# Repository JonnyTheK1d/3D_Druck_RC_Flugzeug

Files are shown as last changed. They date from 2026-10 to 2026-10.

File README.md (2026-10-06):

# 1:8 RC-Flugzeug im Stil einer Cessna 172 – zum Selbstdrucken

Einmotoriger Hochdecker (Tragflächenstreben, Landeklappen, Bugradfahrwerk mit Radverkleidungen, Rückenflosse, Zugpropeller) im Maßstab **1:8** einer Cessna 172,
vollständig als **druckbare STL-Dateien** für Drucker ab **220 × 220 mm** Druckbett, parametrisch erzeugt (Python).

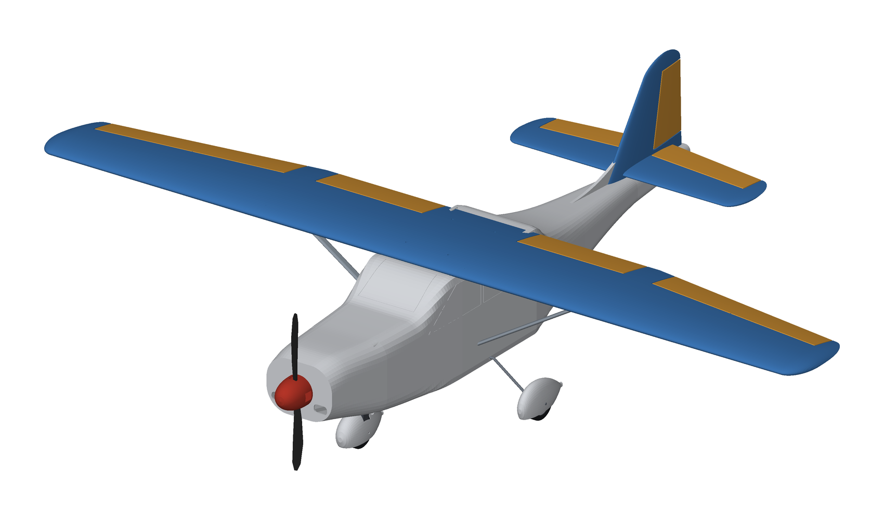
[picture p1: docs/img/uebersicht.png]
Übersicht


> **Status: Entwurf, nicht geflogen.** Geometrie, Druckbarkeit, Ruderfreigang und Schwerpunkt sind rechnerisch geprüft
> (siehe unten), das Flugzeug wurde aber **nicht gebaut und nicht geflogen**. Gewichte sind Schätzungen aus dem Modellvolumen.
> Plane Probe-Drucke und einen vorsichtigen Erstflug ein.

## Eckdaten

| | |
|---|---|
| Vorbild / Maßstab | Cessna 172, 1:8 |
| Spannweite / Länge / Höhe | **1375 mm** / ca. 1030 mm (mit Spinner) / 340 mm |
| Flügel | NACA 2412 (Unterseite ab 25 % eben, druckfreundlich), Tiefe 200 → 140 mm, **25,2 dm²**, Streckung 7,5, 2° Einstellwinkel |
| Leitwerk | Höhenleitwerk 425 mm (NACA 0010), Seitenleitwerk 175 mm hoch (NACA 0009) |
| Steuerung | Quer-, Höhen-, Seitenruder, **Landeklappen**, Gas, steuerbares Bugrad (7 Servos 9 g) |
| Antrieb (Empfehlung) | Außenläufer 28xx ≈ 1000 kV, 30-A-Regler, 3S 2200 mAh, Luftschraube 10×6″ |
<!-- AUTO:eckdaten -->
| Abfluggewicht (Schätzung) | **≈ 1,7 kg** (1,14 kg gedruckt + 0,55 kg Elektronik/Kohlefaser) |
| Flächenbelastung | ≈ 67 g/dm², Überziehgeschwindigkeit ≈ 9 m/s |
| Schwerpunkt (Rechenwert) | 60 mm hinter der Flügelvorderkante ≈ **32 % MAC**, Stabilitätsmaß ≈ 13 % MAC |
| Druckteile | **58 STL-Dateien / 66 Drucke**, größte Grundfläche 205 × 205 mm, höchstes Teil 93 mm |
| Material | ca. 985 g **LW-PLA**, 72 g PETG, 46 g PLA, 35 g TPU (siehe `docs/DRUCKEINSTELLUNGEN.md`) |
<!-- /AUTO:eckdaten -->

Die Auswertung stammt aus `docs/kennzahlen.json` (wird beim Generieren neu geschrieben).

## Ansichten

| | |
|---|---|
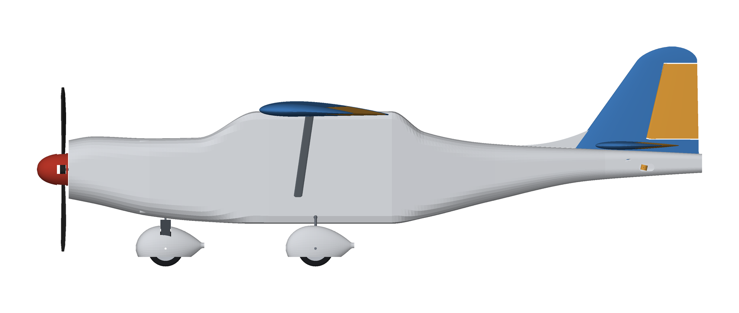
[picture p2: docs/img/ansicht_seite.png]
Seite
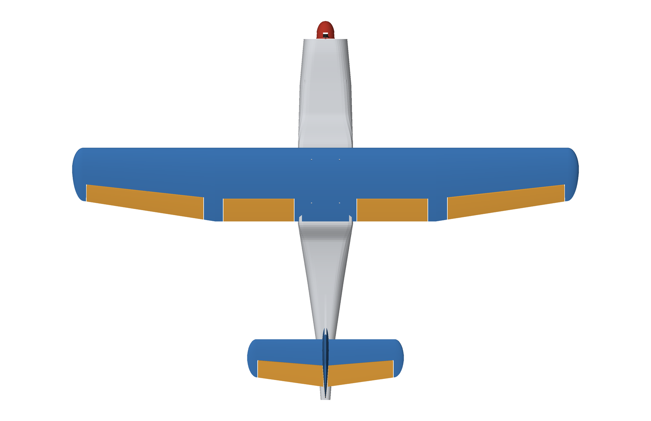
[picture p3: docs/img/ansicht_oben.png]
Oben
|  |  |
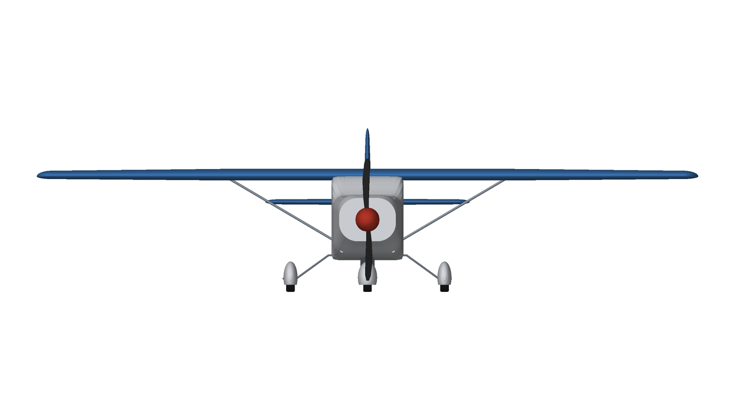
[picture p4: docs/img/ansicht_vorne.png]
Vorne
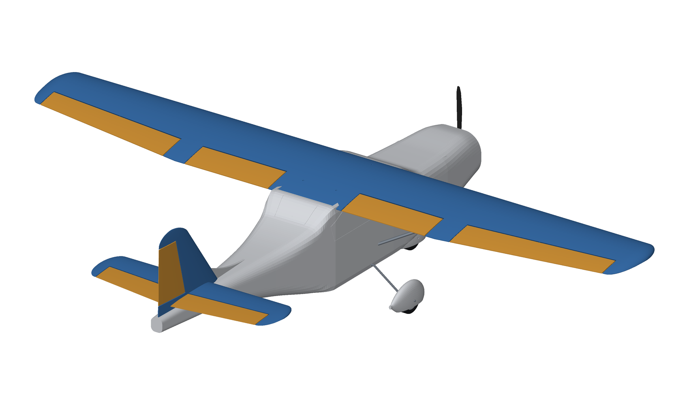
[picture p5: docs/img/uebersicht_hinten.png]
Hinten
|  |  |

## Inhalt des Repositories

| Pfad | Inhalt |
|---|---|
| `stl/` | **Alle druckfertigen STL** (bereits in Druckausrichtung), nach Gruppen: `Fluegel/`, `Querruder/`, `Leitwerk/`, `Rumpf/`, `Antrieb/`, `Fahrwerk/`, `Streben/`, `Kleinteile/` |
| `druckplatten/` | **34 fertig angeordnete Druckplatten (3MF)** für 220 × 220-mm-Betten, nach Material/Einstellung sortiert |
| `docs/DRUCKPLATTEN.md` | Welche Platte mit welchem Material und welchen Slicer-Einstellungen |
| `docs/DRUCKLISTE.md` | Teile, Stückzahl, Material, Druckgröße, Masse |
| `docs/DRUCKEINSTELLUNGEN.md` | Material, Slicer-Einstellungen, Ausrichtung, Nacharbeit |
| `docs/ZUKAUFTEILE.md` | Elektronik, Kohlefaser, Draht, Schrauben mit Maßen |
| `docs/BAUANLEITUNG.md` | Zusammenbau, Schwerpunkt, Ruderausschläge, Erstflug |
| `docs/FERNSTEUERUNG.md` | **Servos, Hebel-Löcher, Gestängelängen, Kanalbelegung, Senderprogrammierung** (aus dem Modell berechnet) |
| `docs/fahrwerk_biegeschablone.pdf` | Biegeschablone Hauptfahrwerk **1:1** (A4 quer) |
| `docs/stueckliste.csv`, `docs/kennzahlen.json` | Teileliste (CSV), Kennzahlen |
| `docs/img/` | Bilder (Ansichten, Explosionszeichnung, Teile-Übersicht) |
| `docs/viewer/` | **3D-Ansicht im Browser** (`index.html` öffnen, siehe unten) |
| `cessna/` | Generator (Python): Maße in `params.py`, Geometrie in `wing.py`, `fuselage.py`, `tail.py`, … |
| `tests/` | Automatische Prüfungen |

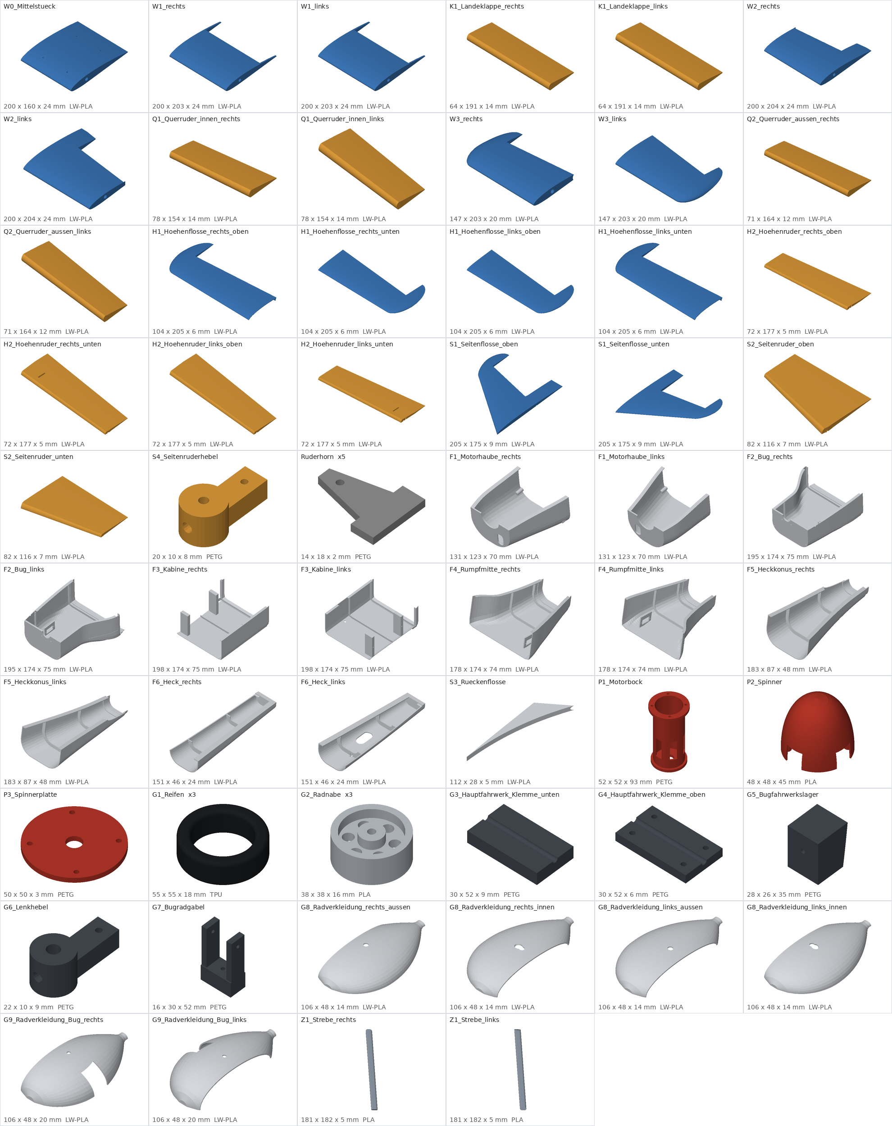
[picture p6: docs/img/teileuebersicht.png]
Teile-Übersicht


## So geht es los (Kurzfassung)

1. **Material besorgen:** ca. 1 kg LW-PLA (Flügel/Rumpf/Leitwerk), etwas PETG, PLA und TPU → `docs/DRUCKEINSTELLUNGEN.md`.
2. **Zukaufteile bestellen** → `docs/ZUKAUFTEILE.md` (Kohlefaser-Rohre 10/8 mm in 660 mm, Federstahldraht, 7 Mikroservos, …).
3. **Zuerst `W0_Mittelstueck` drucken und wiegen** (Soll laut `docs/DRUCKLISTE.md`) – damit Flow/Temperatur für LW-PLA richtig stehen.
4. Alle Teile drucken: die **3MF-Platten in `druckplatten/`** im Slicer öffnen (PrusaSlicer, Bambu Studio, OrcaSlicer, Cura),
   Einstellungen laut `docs/DRUCKPLATTEN.md`, slicen, drucken. Alternativ Einzelteile aus `stl/`. **Keine Stützen** außer
   optional unter der Flügelnase.
5. Zusammenbau nach `docs/BAUANLEITUNG.md` (Flügel → Leitwerk → Rumpf → Antrieb → Fahrwerk → Endmontage).
6. Fernsteuerung einbauen und programmieren → `docs/FERNSTEUERUNG.md` (Kanalplan, Gestängelängen, Ausschläge, Failsafe).
7. Schwerpunkt einstellen (siehe Tabelle oben), Ruder prüfen, **vorsichtig** einfliegen.

## 3D-Ansicht im Browser

`docs/viewer/index.html` zeigt das komplette Flugzeug interaktiv (Modell: `flugzeug.glb`, für die Seite base64-kodiert in `flugzeug.glb.txt`) (drehen, zoomen, Explosionsansicht, Baugruppen
ein-/ausblenden, Ruder bewegen). Auch die Zukaufteile sind zu sehen: Fahrwerksdrähte, Holm, Motor, Akku, Regler, Empfänger und die
7 Servos. Servohebel und Gestänge bewegen sich beim Ruderausschlag mit, das Bugrad lenkt mit dem Seitenruder.
„Rumpf durchsichtig“ zeigt die Anlenkungen im Rumpf. Wegen der Browser-Sicherheit die Seite über einen kleinen Webserver öffnen:

```bash
python -m http.server -d docs/viewer 8000   # dann http://localhost:8000 aufrufen
```

## Konstruktionsprinzip

* **Hohlbauweise für LW-PLA:** Außenhaut 1,1 mm (Flügel), 1,2 mm (Rumpf), 0,85 mm (Leitwerk) mit Rippen/Spanten;
  Holm = **CFK-Rohr 10/8 mm** durch alle Flügelabschnitte (gedruckte Holmhülsen), Verbinderstab in der Mitte.
* **Druckbett 220 × 220 mm:** Der Flügel besteht aus 4 Abschnitten je Seite/Mitte (je ≤ 202 mm Spannweite), der Rumpf aus
  6 Segmenten × links/rechts mit **Steckmuffen**, die Leitwerksflächen sind in Ober-/Unterschale geteilt.
* **Das Flügelmittelstück ist das Kabinendach** (wie bei der Cessna): Der Rumpf hat unter dem Flügel eine offene Kabine mit
  Spantbalken; der Flügel liegt in einem passgenauen Sattel und wird mit 4 Schrauben gehalten. Der Akku sitzt im Bugfach
  (Einschub von der Kabine aus) → wenige bewegliche Teile, Akku in Schwerpunktnähe.
* **Ruder mit Rundnase + Hohlkehle:** Querruder, Höhen- und Seitenruder lassen sich in der CAD-Prüfung um ±30° ausschlagen,
  ohne an Festteile zu stoßen (Scharnier: Gewebeband beidseitig).
* **Landeklappen** im Innenflügel (0–35° nach unten, eigenes Servo je Seite), **Radverkleidungen** für alle drei Räder
  und eine **Rückenflosse** wie bei der späten 172 – alle drei optional, aber typisch Cessna.
* **Fenster** sind als flache Gravuren (Lackiermaske) in den Rumpf eingearbeitet; Streben sind kosmetisch.
* **Druckfreundlich:** Alle Rumpfwände sind eben (stückweise linear verjüngt), damit sie flach auf dem Bett liegen; Teile
  sind so geteilt, dass keine Stützen nötig sind.

## Prüfungen (automatisch, `pytest`)

* alle Teile gültige geschlossene Volumenkörper, passen auf 220 × 220 × 250 mm (mit 4 mm Rand);
* **keine Überschneidungen** im Zusammenbau (paarweise Prüfung, inkl. Sättel für Flügel/Leitwerk);
* Ruderfreigang ±30° (Landeklappen ±35°); Holm liegt innerhalb des Profils;
* Schwerpunkt 22–34 % MAC, Stabilitätsmaß ≥ 8 %, Hauptfahrwerk ≥ 15 mm hinter dem Schwerpunkt;
* STL-Export wasserdicht (nach Rundung auf float32, wie beim Slicer), Einzelteile mit Boden auf z = 0.

## Anpassen und neu erzeugen

```bash
pip install -r requirements.txt
python -m cessna.build            # erzeugt STL, Druckliste, Bilder, Kennzahlen (~25 s)
python -m cessna.build --no-images --overlaps    # schneller Check inkl. Überschneidungsprüfung
python -m pytest -q tests         # Prüfungen
```

Alle Maße stehen in `cessna/params.py` (Flügel, Rumpftabelle, Leitwerk, Fahrwerk, Wandstärken, Druckbett). Der Generator
liefert zu jedem Lauf die Kennzahlen (Masse, Schwerpunkt, Neutralpunkt). Kleinere Druckbetten brauchen eine feinere
Teilung (Segmentgrenzen in `FUSE_SEGMENTS`, Abschnittsbreite `WING_PANEL_SPAN`); die Prüfung meldet jedes Teil, das nicht passt.

## Bekannte Grenzen / offene Punkte

* **Nicht geflogen.** Neutralpunkt/Stabilität sind Näherungsrechnungen (Standardmethode), keine Strömungsrechnung.
* Gewichte sind aus dem Volumen geschätzt (LW-PLA 0,55 g/cm³). Echte Teile können ±20 % abweichen → Schwerpunkt nach dem Bau
  ausmessen (Akkulage, Trimmblei im Bug).
* Der Flügel ist **einteilig** (1375 mm), nicht teilbar. Die Landeklappen sind einfache Drehklappen (keine Fowler-Klappen wie beim Original).
* Profil weicht für den Druck vom Original ab (flache Unterseite hinter 25 % Tiefe); die Nasenunterseite braucht ggf. einen
  kleinen Stützkeil oder Brim.
* Die Streben sind nur aufgeklebt (kosmetisch). Die Ruderscharniere sind Gewebeband (kein Kugelscharnier).
* Die Heckgestänge laufen in Kanälen durch die Spanten: Höhenruder als Bowdenzug mit schrägem Austritt links,
  Seitenruder über eine Ruderwelle in der Scharnierachse und den Hebel `S4` (Gestänge bleibt im Rumpf).
* Keine Lizenz festgelegt – wenn du das Repository öffentlich machst, lege eine passende Lizenz fest.

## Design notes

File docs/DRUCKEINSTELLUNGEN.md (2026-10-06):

# Druckeinstellungen und Material

> **Fertige Druckplatten:** `druckplatten/*.3mf` enthält alle Teile, nach Material und Einstellung sortiert und auf
> 220 × 220 mm angeordnet. Übersicht und Einstellungen je Platte: [`DRUCKPLATTEN.md`](DRUCKPLATTEN.md).

Alle STL-Dateien liegen in **Druckausrichtung** vor (kein Drehen nötig, Teile liegen auf z = 0). Größte Grundfläche:
205 × 205 mm (Flügelabschnitte, Leitwerk), höchstes Teil 93 mm (Motorbock) → passt auf Betten ab **220 × 220 mm**
(Ender 3, Prusa MK3/MK4, Bambu A1/P1 usw.). Jedes Teil hält mindestens 4 mm Rand ein.

## Materialübersicht

<!-- AUTO:material -->
| Material | Teile | Masse |
|---|---|---:|
| **LW-PLA** (schäumend) | Flügel, Querruder, Rumpf (6 Segmente), Leitwerk | ca. 985 g |
| **PETG** | Motorbock, Spinnerplatte, Fahrwerksklemmen, Bugfahrwerkslager, Gabel, Lenkhebel, Ruderhörner | ca. 72 g |
| **PLA** | Spinnerkegel, Radnaben, Streben | ca. 46 g |
| **TPU 95A** | 3 Reifen | ca. 35 g |
<!-- /AUTO:material -->

> Ohne LW-PLA geht es auch mit normalem PLA, dann wird das Flugzeug aber etwa **doppelt so schwer** (Flügel/Rumpf-Schalen
> wiegen dann ca. 2,0 kg) und fliegt nicht mehr sinnvoll. Für PLA müsste man die Wandstärken in `cessna/params.py`
> (`WALL_WING`, `WALL_FUSE`) auf ca. 0,6 mm verringern und neu generieren; dafür ist dieser Entwurf nicht optimiert.

## LW-PLA (Flügel, Rumpf, Leitwerk)

LW-PLA schäumt bei hoher Temperatur auf und hat dann nur ca. 0,5 g/cm³. Das Modell geht von **ausgeschäumten** Wandstärken aus:
Flügel 1,1 mm, Rumpf 1,2 mm, Leitwerk 0,85 mm (Parameter in `cessna/params.py` bzw. `tail.py`).

| Einstellung | Richtwert |
|---|---|
| Düse | 0,4 mm (0,6 mm geht auch, dann Linienbreite anpassen) |
| Temperatur | 230–250 °C (je nach Hersteller; höher = mehr schäumen = leichter) |
| Fluss (Flow) | **ca. 50–65 %**: so kalibrieren, dass ein Einzelwand-Würfel die Modellwandstärke ergibt (messen!) |
| Schichthöhe | 0,2–0,28 mm |
| Wände | so viele, dass die Wandstärke erreicht wird (z. B. 2 Wände bei 0,55 mm Linienbreite = 1,1 mm) |
| Füllung | **0 %** (Hohlbauweise); Boden/Deckel je 3 Schichten |
| „Dünne Wände erkennen“ / Gap-Fill | **an** (Rippen sind 1,2 mm, Leitwerk 0,85 mm dick) |
| Rückzug | aus oder sehr klein (LW-PLA fadet sonst stark) |
| Geschwindigkeit | 35–60 mm/s |
| Lüfter | 50–100 % |
| Stützen | **nur** unter der Flügelnase (optional, siehe unten); sonst keine; Brim 3–5 mm bei Flügelabschnitten |
| Z-Naht | hinten/zufällig, nicht an der Vorderkante |

**Erst wiegen:** Drucke zuerst `W0_Mittelstueck` (rechnerisch ca. 56 g) und wiege es. Weicht die Masse deutlich ab,
Flow/Temperatur nachstellen, bevor du alles druckst. Die Gesamtmasse bestimmt Schwerpunkt und Flugleistung.

## Ausrichtung je Bauteilgruppe (bereits in den STL)

* **Flügelabschnitte (W0–W3)** liegen auf der flachen Unterseite (Profil hinter 25 % Tiefe eben, um 3,1° gekippt).
  Nur die Nasenunterseite hebt sich vorn vom Bett ab (bei 10 % Tiefe 2,5 mm, an der Nasenspitze ca. 5 mm): dort ist ein
  schmaler Stützkeil „nur vom Druckbett aus" sinnvoll oder ein Brim; im Zweifel zuerst ein kurzes Probestück drucken.
  Die Hohlräume sind rundum geschlossen, Rippen verhindern das Durchhängen der Oberseite (Rippenabstand ca. 34 mm).
* **Querruder** liegen auf der Unterseite; die Rundnase ist massiv.
* **Leitwerksflächen** sind in **Ober- und Unterschale** geteilt (symmetrische Profile wären sonst nur mit Stützen
  druckbar). Jede Schale liegt mit der ebenen Schnittfläche auf dem Bett; ein Klebeflansch umläuft die Naht.
  Seitenflosse/-ruder: obere Schale = linke Seite, untere = rechte Seite.
* **Rumpf** besteht aus 6 Segmenten, jeweils links/rechts. Gedruckt wird **mit der Außenwand nach unten**, die offene
  Teilungsebene zeigt nach oben. Die Seitenwand ist eben und liegt bei jedem Segment (gegebenenfalls leicht gekippt, bis 8°)
  vollflächig auf dem Bett. Innenteile (Spanten, Servoböden, Domen) wachsen von der Wand nach oben. Überhänge treten nur
  an den Rundungen zur Dach-/Bauchlinie auf.
* **Motorbock** steht auf dem hinteren Flansch, **Spinnerkegel** mit offener Seite nach unten, **Streben** liegen
  diagonal (248 mm lang), **Reifen** liegen flach (TPU langsam, 15–25 mm/s, Rückzug aus).

## PETG / PLA / TPU

| Teil | Wände | Füllung | Hinweis |
|---|---:|---|---|
| Motorbock (PETG) | 3 | 30 % | Wärmebeständig, 245 °C/80 °C Bett |
| Fahrwerksteile (PETG) | 4 | 40 % | |
| Spinner/Streben/Naben (PLA) | 2–3 | 15–40 % | Spinnerkegel: 1,2 mm Wand, offene Seite nach unten |
| Reifen (TPU 95A) | 2 | 10 % | langsam drucken |

## Nacharbeit

* Brims/Fäden entfernen; Klebeflächen (Ränder der Schalen, Rippenränder) leicht anschleifen.
* Vor dem Kleben **alles trocken zusammenstecken** (Steckmuffen am Rumpf, Holmrohre durch die Flügelabschnitte).
* Spinner und Hauben leicht verspachteln/schleifen, bevor lackiert wird.

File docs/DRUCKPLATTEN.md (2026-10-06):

# Druckplatten (3MF, fertig angeordnet)

Alle druckbaren Teile, nach **Material und Slicer-Einstellung** auf Platten für ein **220 × 220-mm-Bett**
verteilt (Ender 3, Prusa MK3/MK4, Bambu A1/P1/X1, Voron, …). Die Dateien liegen in `druckplatten/`.
Die Teile stehen in Druckausrichtung und mit 8 mm Abstand (Platz für Brim). Größere Betten: einfach
mehrere Platten im Slicer zusammenlegen oder „Anordnen“ drücken.

**So geht's:** 3MF-Datei im Slicer öffnen (PrusaSlicer, Bambu Studio, OrcaSlicer, Cura) → Druckerprofil wählen →
Einstellungen aus der Spalte „Einstellung“ setzen → slicen → G-Code/Druckauftrag an den Drucker.
Fragt der Slicer, ob das Objekt aus mehreren Teilen besteht: **Nein** (jede Datei enthält einzelne Objekte).

> Zuerst **Platte 01** (`W0_Mittelstueck`) drucken und wiegen: Soll ca. 57 g. Weicht das stark ab,
> Fluss/Temperatur für LW-PLA nachstellen (siehe `docs/DRUCKEINSTELLUNGEN.md`), bevor du den Rest druckst.

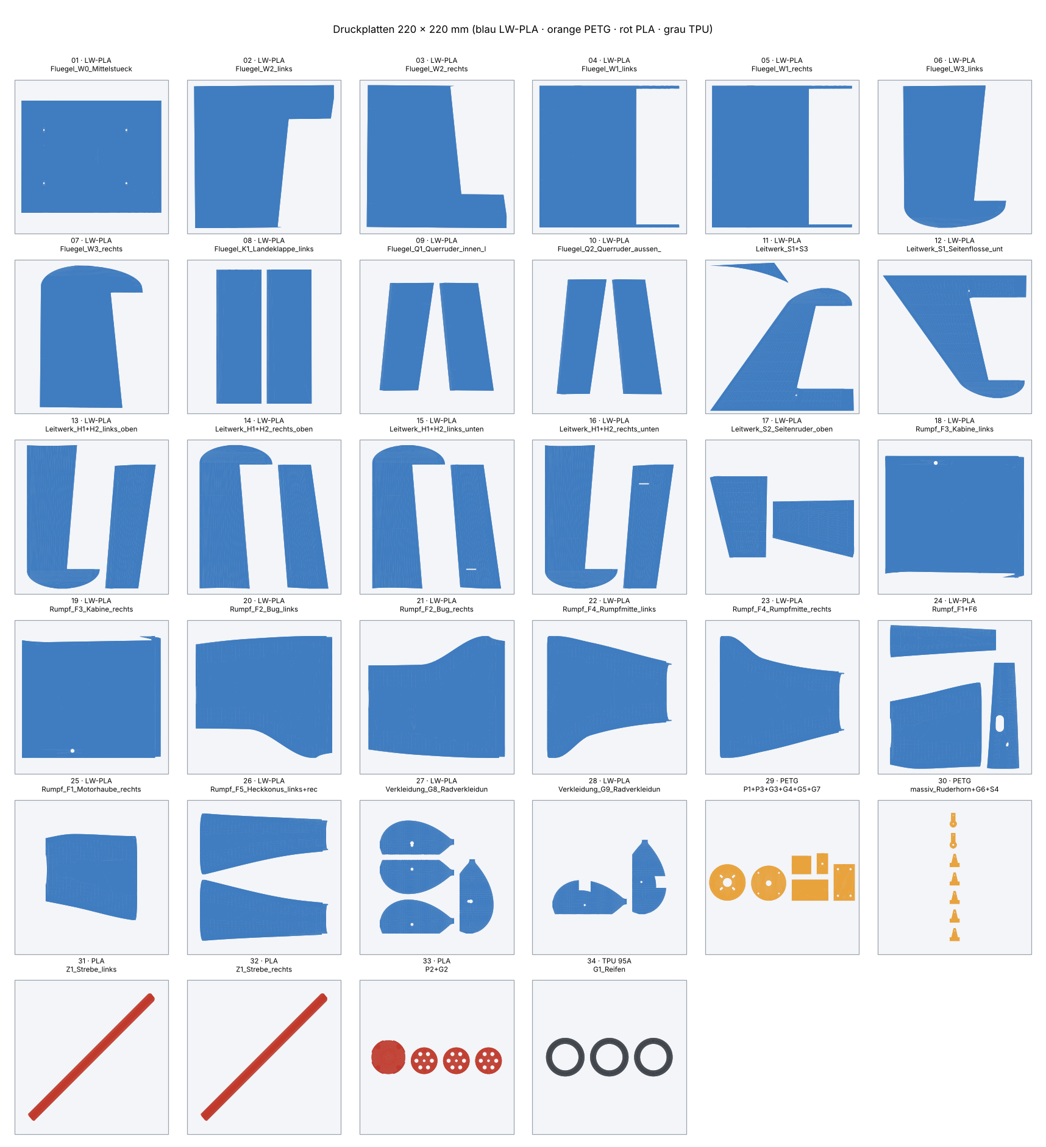
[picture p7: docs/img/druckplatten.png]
Druckplatten


| Platte | Datei | Material | Einstellung | Teile | Masse | Höhe |
|---:|---|---|---|---|---:|---:|
| 01 | `01_LW-PLA_Fluegel_W0_Mittelstueck.3mf` | LW-PLA | Wand 1,1 mm, 0 % Füllung, Boden/Deckel 3 Schichten, Brim 3–5 mm | `W0_Mittelstueck` | 57 g | 24 mm |
| 02 | `02_LW-PLA_Fluegel_W2_links.3mf` | LW-PLA | Wand 1,1 mm, 0 % Füllung, Boden/Deckel 3 Schichten, Brim 3–5 mm | `W2_links` | 53 g | 24 mm |
| 03 | `03_LW-PLA_Fluegel_W2_rechts.3mf` | LW-PLA | Wand 1,1 mm, 0 % Füllung, Boden/Deckel 3 Schichten, Brim 3–5 mm | `W2_rechts` | 53 g | 24 mm |
| 04 | `04_LW-PLA_Fluegel_W1_links.3mf` | LW-PLA | Wand 1,1 mm, 0 % Füllung, Boden/Deckel 3 Schichten, Brim 3–5 mm | `W1_links` | 55 g | 24 mm |
| 05 | `05_LW-PLA_Fluegel_W1_rechts.3mf` | LW-PLA | Wand 1,1 mm, 0 % Füllung, Boden/Deckel 3 Schichten, Brim 3–5 mm | `W1_rechts` | 55 g | 24 mm |
| 06 | `06_LW-PLA_Fluegel_W3_links.3mf` | LW-PLA | Wand 1,1 mm, 0 % Füllung, Boden/Deckel 3 Schichten, Brim 3–5 mm | `W3_links` | 42 g | 20 mm |
| 07 | `07_LW-PLA_Fluegel_W3_rechts.3mf` | LW-PLA | Wand 1,1 mm, 0 % Füllung, Boden/Deckel 3 Schichten, Brim 3–5 mm | `W3_rechts` | 42 g | 20 mm |
| 08 | `08_LW-PLA_Fluegel_K1_Landeklappe_links+rechts.3mf` | LW-PLA | Wand 1,1 mm, 0 % Füllung, Boden/Deckel 3 Schichten, Brim 3–5 mm | `K1_Landeklappe_links`, `K1_Landeklappe_rechts` | 61 g | 14 mm |
| 09 | `09_LW-PLA_Fluegel_Q1_Querruder_innen_links+rechts.3mf` | LW-PLA | Wand 1,1 mm, 0 % Füllung, Boden/Deckel 3 Schichten, Brim 3–5 mm | `Q1_Querruder_innen_links`, `Q1_Querruder_innen_rechts` | 43 g | 14 mm |
| 10 | `10_LW-PLA_Fluegel_Q2_Querruder_aussen_links+rechts.3mf` | LW-PLA | Wand 1,1 mm, 0 % Füllung, Boden/Deckel 3 Schichten, Brim 3–5 mm | `Q2_Querruder_aussen_links`, `Q2_Querruder_aussen_rechts` | 37 g | 12 mm |
| 11 | `11_LW-PLA_Leitwerk_S1+S3.3mf` | LW-PLA | Wand 0,85 mm, 0 % Füllung, Boden/Deckel 3 Schichten, „dünne Wände“ an | `S1_Seitenflosse_oben`, `S3_Rueckenflosse` | 13 g | 9 mm |
| 12 | `12_LW-PLA_Leitwerk_S1_Seitenflosse_unten.3mf` | LW-PLA | Wand 0,85 mm, 0 % Füllung, Boden/Deckel 3 Schichten, „dünne Wände“ an | `S1_Seitenflosse_unten` | 10 g | 9 mm |
| 13 | `13_LW-PLA_Leitwerk_H1+H2_links_oben.3mf` | LW-PLA | Wand 0,85 mm, 0 % Füllung, Boden/Deckel 3 Schichten, „dünne Wände“ an | `H1_Hoehenflosse_links_oben`, `H2_Hoehenruder_links_oben` | 16 g | 6 mm |
| 14 | `14_LW-PLA_Leitwerk_H1+H2_rechts_oben.3mf` | LW-PLA | Wand 0,85 mm, 0 % Füllung, Boden/Deckel 3 Schichten, „dünne Wände“ an | `H1_Hoehenflosse_rechts_oben`, `H2_Hoehenruder_rechts_oben` | 16 g | 6 mm |
| 15 | `15_LW-PLA_Leitwerk_H1+H2_links_unten.3mf` | LW-PLA | Wand 0,85 mm, 0 % Füllung, Boden/Deckel 3 Schichten, „dünne Wände“ an | `H1_Hoehenflosse_links_unten`, `H2_Hoehenruder_links_unten` | 16 g | 6 mm |
| 16 | `16_LW-PLA_Leitwerk_H1+H2_rechts_unten.3mf` | LW-PLA | Wand 0,85 mm, 0 % Füllung, Boden/Deckel 3 Schichten, „dünne Wände“ an | `H1_Hoehenflosse_rechts_unten`, `H2_Hoehenruder_rechts_unten` | 16 g | 6 mm |
| 17 | `17_LW-PLA_Leitwerk_S2_Seitenruder_oben+unten.3mf` | LW-PLA | Wand 0,85 mm, 0 % Füllung, Boden/Deckel 3 Schichten, „dünne Wände“ an | `S2_Seitenruder_unten`, `S2_Seitenruder_oben` | 14 g | 7 mm |
| 18 | `18_LW-PLA_Rumpf_F3_Kabine_links.3mf` | LW-PLA | Wand 1,2 mm, 0 % Füllung, Boden/Deckel 3 Schichten | `F3_Kabine_links` | 58 g | 75 mm |
| 19 | `19_LW-PLA_Rumpf_F3_Kabine_rechts.3mf` | LW-PLA | Wand 1,2 mm, 0 % Füllung, Boden/Deckel 3 Schichten | `F3_Kabine_rechts` | 58 g | 75 mm |
| 20 | `20_LW-PLA_Rumpf_F2_Bug_links.3mf` | LW-PLA | Wand 1,2 mm, 0 % Füllung, Boden/Deckel 3 Schichten | `F2_Bug_links` | 55 g | 75 mm |
| 21 | `21_LW-PLA_Rumpf_F2_Bug_rechts.3mf` | LW-PLA | Wand 1,2 mm, 0 % Füllung, Boden/Deckel 3 Schichten | `F2_Bug_rechts` | 54 g | 75 mm |
| 22 | `22_LW-PLA_Rumpf_F4_Rumpfmitte_links.3mf` | LW-PLA | Wand 1,2 mm, 0 % Füllung, Boden/Deckel 3 Schichten | `F4_Rumpfmitte_links` | 29 g | 74 mm |
| 23 | `23_LW-PLA_Rumpf_F4_Rumpfmitte_rechts.3mf` | LW-PLA | Wand 1,2 mm, 0 % Füllung, Boden/Deckel 3 Schichten | `F4_Rumpfmitte_rechts` | 29 g | 74 mm |
| 24 | `24_LW-PLA_Rumpf_F1+F6.3mf` | LW-PLA | Wand 1,2 mm, 0 % Füllung, Boden/Deckel 3 Schichten | `F1_Motorhaube_links`, `F6_Heck_links`, `F6_Heck_rechts` | 38 g | 70 mm |
| 25 | `25_LW-PLA_Rumpf_F1_Motorhaube_rechts.3mf` | LW-PLA | Wand 1,2 mm, 0 % Füllung, Boden/Deckel 3 Schichten | `F1_Motorhaube_rechts` | 23 g | 70 mm |
| 26 | `26_LW-PLA_Rumpf_F5_Heckkonus_links+rechts.3mf` | LW-PLA | Wand 1,2 mm, 0 % Füllung, Boden/Deckel 3 Schichten | `F5_Heckkonus_links`, `F5_Heckkonus_rechts` | 31 g | 48 mm |
| 27 | `27_LW-PLA_Verkleidung_G8_Radverkleidung_aussen+innen+links+rechts.3mf` | LW-PLA | Wand 1,0 mm, 0 % Füllung | `G8_Radverkleidung_links_aussen`, `G8_Radverkleidung_links_innen`, `G8_Radverkleidung_rechts_aussen`, `G8_Radverkleidung_rechts_innen` | 10 g | 14 mm |
| 28 | `28_LW-PLA_Verkleidung_G9_Radverkleidung_Bug_links+rechts.3mf` | LW-PLA | Wand 1,0 mm, 0 % Füllung | `G9_Radverkleidung_Bug_links`, `G9_Radverkleidung_Bug_rechts` | 5 g | 20 mm |
| 29 | `29_PETG_P1+P3+G3+G4+G5+G7.3mf` | PETG | 4 Wände, 40 % Füllung (Gyroid), 245 °C / Bett 80 °C | `P1_Motorbock`, `P3_Spinnerplatte`, `G3_Hauptfahrwerk_Klemme_unten`, `G4_Hauptfahrwerk_Klemme_oben`, `G5_Bugfahrwerkslager`, `G7_Bugradgabel` | 68 g | 93 mm |
| 30 | `30_PETG_massiv_Ruderhorn+G6+S4.3mf` | PETG | 100 % Füllung (Hebel und Ruderhörner müssen steif sein) | `Ruderhorn` ×5, `G6_Lenkhebel`, `S4_Seitenruderhebel` | 4 g | 9 mm |
| 31 | `31_PLA_Z1_Strebe_links.3mf` | PLA | 3 Wände, 20 % Füllung | `Z1_Strebe_links` | 8 g | 5 mm |
| 32 | `32_PLA_Z1_Strebe_rechts.3mf` | PLA | 3 Wände, 20 % Füllung | `Z1_Strebe_rechts` | 8 g | 5 mm |
| 33 | `33_PLA_P2+G2.3mf` | PLA | 3 Wände, 20 % Füllung | `P2_Spinner`, `G2_Radnabe` ×3 | 29 g | 45 mm |
| 34 | `34_TPU_G1_Reifen.3mf` | TPU 95A | 2 Wände, 10 % Füllung, 15–25 mm/s, Rückzug aus | `G1_Reifen` ×3 | 35 g | 18 mm |

**34 Platten**, LW-PLA: ca. 985 g, PETG: ca. 72 g, PLA: ca. 46 g, TPU 95A: ca. 35 g (Filamentverbrauch etwas höher: Brim, Fehldrucke).

Einzelteile als STL (gleiche Ausrichtung) liegen in `stl/`, die Teileliste in `docs/DRUCKLISTE.md`.

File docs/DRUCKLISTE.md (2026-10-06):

# Druckliste

Alle STL-Dateien liegen bereits in **Druckausrichtung** vor (Teil liegt auf z = 0). Menge = Anzahl Drucke.
Masse = Schätzung aus dem Modellvolumen (LW-PLA 0,55 g/cm³ als Hohlschale; Massivteile mit Füllfaktor).

## Flügel

| Teil | Menge | Material | Größe x·y·z [mm] | Masse [g] | Hinweis |
|---|---:|---|---|---:|---|
| `W0_Mittelstueck` | 1 | LW-PLA | 200 · 160 · 24 | 57.5 | 4 Schraubendome für M3, Kabelaustritt unten |
| `W1_rechts` | 1 | LW-PLA | 200 · 203 · 24 | 54.6 | mit Servoschacht für das Klappenservo |
| `W1_links` | 1 | LW-PLA | 200 · 203 · 24 | 54.6 | mit Servoschacht für das Klappenservo |
| `W2_rechts` | 1 | LW-PLA | 200 · 204 · 24 | 52.6 | mit Servoschacht für 9-g-Servo (Querruder) |
| `W2_links` | 1 | LW-PLA | 200 · 204 · 24 | 52.6 | mit Servoschacht für 9-g-Servo (Querruder) |
| `W3_rechts` | 1 | LW-PLA | 147 · 203 · 20 | 41.6 | mit abgerundetem Randbogen |
| `W3_links` | 1 | LW-PLA | 147 · 203 · 20 | 41.6 | mit abgerundetem Randbogen |

## Querruder

| Teil | Menge | Material | Größe x·y·z [mm] | Masse [g] | Hinweis |
|---|---:|---|---|---:|---|
| `K1_Landeklappe_rechts` | 1 | LW-PLA | 64 · 191 · 14 | 30.5 | Landeklappe 0..35° nach unten; Horn-Schlitz an der Unterseite |
| `K1_Landeklappe_links` | 1 | LW-PLA | 64 · 191 · 14 | 30.5 | Landeklappe 0..35° nach unten; Horn-Schlitz an der Unterseite |
| `Q1_Querruder_innen_rechts` | 1 | LW-PLA | 78 · 154 · 14 | 21.5 | Horn-Schlitz an der Unterseite; mit Q2 zu einem Ruder verkleben |
| `Q1_Querruder_innen_links` | 1 | LW-PLA | 78 · 154 · 14 | 21.5 | Horn-Schlitz an der Unterseite; mit Q2 zu einem Ruder verkleben |
| `Q2_Querruder_aussen_rechts` | 1 | LW-PLA | 71 · 164 · 12 | 18.3 |  |
| `Q2_Querruder_aussen_links` | 1 | LW-PLA | 71 · 164 · 12 | 18.3 |  |

## Leitwerk

| Teil | Menge | Material | Größe x·y·z [mm] | Masse [g] | Hinweis |
|---|---:|---|---|---:|---|
| `H1_Hoehenflosse_rechts_oben` | 1 | LW-PLA | 104 · 205 · 6 | 7.9 | CFK-Stab Ø4 als Holm durch beide Hälften |
| `H1_Hoehenflosse_rechts_unten` | 1 | LW-PLA | 104 · 205 · 6 | 7.9 | CFK-Stab Ø4 als Holm durch beide Hälften |
| `H1_Hoehenflosse_links_oben` | 1 | LW-PLA | 104 · 205 · 6 | 7.9 | CFK-Stab Ø4 als Holm durch beide Hälften |
| `H1_Hoehenflosse_links_unten` | 1 | LW-PLA | 104 · 205 · 6 | 7.9 | CFK-Stab Ø4 als Holm durch beide Hälften |
| `H2_Hoehenruder_rechts_oben` | 1 | LW-PLA | 72 · 177 · 5 | 8.0 | 2-mm-CFK-Stab verbindet beide Hälften; Horn nur an einer Seite |
| `H2_Hoehenruder_rechts_unten` | 1 | LW-PLA | 72 · 177 · 5 | 8.0 | 2-mm-CFK-Stab verbindet beide Hälften; Horn nur an einer Seite |
| `H2_Hoehenruder_links_oben` | 1 | LW-PLA | 72 · 177 · 5 | 8.0 | 2-mm-CFK-Stab verbindet beide Hälften; Horn nur an einer Seite |
| `H2_Hoehenruder_links_unten` | 1 | LW-PLA | 72 · 177 · 5 | 8.0 | 2-mm-CFK-Stab verbindet beide Hälften; Horn nur an einer Seite |
| `S1_Seitenflosse_oben` | 1 | LW-PLA | 205 · 175 · 9 | 10.3 | unterste 15 mm stecken im Heck (Schlitz im Rumpf) |
| `S1_Seitenflosse_unten` | 1 | LW-PLA | 205 · 175 · 9 | 10.3 | unterste 15 mm stecken im Heck (Schlitz im Rumpf) |
| `S2_Seitenruder_oben` | 1 | LW-PLA | 82 · 116 · 7 | 6.9 |  |
| `S2_Seitenruder_unten` | 1 | LW-PLA | 82 · 116 · 7 | 6.9 |  |
| `S4_Seitenruderhebel` | 1 | PETG | 20 · 10 · 8 | 1.1 | klemmt mit M3-Madenschraube auf der Ø2-Ruderwelle; Zugang durch die Wartungsöffnung links im Heck |
| `S3_Rueckenflosse` | 1 | LW-PLA | 112 · 28 · 5 | 2.3 | flach drucken; auf den Rumpfrücken (F5) und an die Vorderkante der Seitenflosse kleben |

## Kleinteile

| Teil | Menge | Material | Größe x·y·z [mm] | Masse [g] | Hinweis |
|---|---:|---|---|---:|---|
| `Ruderhorn` | 5 | PETG | 14 · 18 · 2 | 0.3 | je 1x Querruder links/rechts, Landeklappe links/rechts, Höhenruder (links unten) |

## Rumpf

| Teil | Menge | Material | Größe x·y·z [mm] | Masse [g] | Hinweis |
|---|---:|---|---|---:|---|
| `F1_Motorhaube_rechts` | 1 | LW-PLA | 131 · 123 · 70 | 23.2 |  |
| `F1_Motorhaube_links` | 1 | LW-PLA | 131 · 123 · 70 | 23.2 |  |
| `F2_Bug_rechts` | 1 | LW-PLA | 195 · 174 · 75 | 54.3 | mit Steckmuffe nach hinten |
| `F2_Bug_links` | 1 | LW-PLA | 195 · 174 · 75 | 55.1 | mit Steckmuffe nach hinten |
| `F3_Kabine_rechts` | 1 | LW-PLA | 198 · 174 · 75 | 57.5 | mit Steckmuffe nach hinten |
| `F3_Kabine_links` | 1 | LW-PLA | 198 · 174 · 75 | 57.5 | mit Steckmuffe nach hinten |
| `F4_Rumpfmitte_rechts` | 1 | LW-PLA | 178 · 174 · 74 | 29.0 | mit Steckmuffe nach hinten |
| `F4_Rumpfmitte_links` | 1 | LW-PLA | 178 · 174 · 74 | 29.0 | mit Steckmuffe nach hinten |
| `F5_Heckkonus_rechts` | 1 | LW-PLA | 183 · 87 · 48 | 15.4 | mit Steckmuffe nach hinten |
| `F5_Heckkonus_links` | 1 | LW-PLA | 183 · 87 · 48 | 15.4 | mit Steckmuffe nach hinten |
| `F6_Heck_rechts` | 1 | LW-PLA | 151 · 46 · 24 | 7.3 |  |
| `F6_Heck_links` | 1 | LW-PLA | 151 · 46 · 24 | 7.1 |  |

## Antrieb

| Teil | Menge | Material | Größe x·y·z [mm] | Masse [g] | Hinweis |
|---|---:|---|---|---:|---|
| `P1_Motorbock` | 1 | PETG | 52 · 52 · 93 | 15.3 | Motor vorn mit 4x M3 anschrauben, hinten mit 4x M3 an den Brandschott; Hitze -> PETG |
| `P2_Spinner` | 1 | PLA | 48 · 48 · 45 | 9.7 | offene Seite nach unten drucken; 4x M2.5x10 Blechschrauben in die Domen |
| `P3_Spinnerplatte` | 1 | PETG | 50 · 50 · 3 | 7.2 | mit Mitnehmer/Propelleradapter verschrauben |

## Fahrwerk

| Teil | Menge | Material | Größe x·y·z [mm] | Masse [g] | Hinweis |
|---|---:|---|---|---:|---|
| `G1_Reifen` | 3 | TPU | 55 · 55 · 18 | 3.9 | TPU 95A, 2 Hauptreifen + 1 Bugreifen (1-2 mm Wand reicht) |
| `G2_Radnabe` | 3 | PLA | 38 · 38 · 16 | 2.1 | Reifen aufkleben (Sekundenkleber); Achsbohrung 4,2 mm (Haupt), Bugrad auf 3 mm aufbohren |
| `G3_Hauptfahrwerk_Klemme_unten` | 1 | PETG | 30 · 52 · 9 | 10.1 | auf den Rumpfboden kleben; Draht 4 mm Federstahl |
| `G4_Hauptfahrwerk_Klemme_oben` | 1 | PETG | 30 · 52 · 6 | 6.5 | 2x M3x12 Blechschrauben in die Bohrungen des unteren Blocks |
| `G5_Bugfahrwerkslager` | 1 | PETG | 28 · 26 · 35 | 17.4 | auf Rumpfboden und Brandschott kleben; 3-mm-Federstahl, Messingrohr 4/3 optional |
| `G6_Lenkhebel` | 1 | PETG | 22 · 10 · 9 | 1.2 | M3-Madenschraube klemmt auf dem 3-mm-Bugfahrwerksdraht |
| `G7_Bugradgabel` | 1 | PETG | 16 · 30 · 52 | 11.8 | Bruecke liegt auf dem Druckbett; 3-mm-Draht einkleben, Achse 3-mm-Stab (Stellringe) |
| `G8_Radverkleidung_rechts_aussen` | 1 | LW-PLA | 106 · 48 · 14 | 2.4 | Radverkleidung (optional); Hälften verkleben, auf Achse stecken, mit Sekundenkleber am Draht sichern |
| `G8_Radverkleidung_rechts_innen` | 1 | LW-PLA | 106 · 48 · 14 | 2.4 | Radverkleidung (optional); Hälften verkleben, auf Achse stecken, mit Sekundenkleber am Draht sichern |
| `G8_Radverkleidung_links_aussen` | 1 | LW-PLA | 106 · 48 · 14 | 2.4 | Radverkleidung (optional); Hälften verkleben, auf Achse stecken, mit Sekundenkleber am Draht sichern |
| `G8_Radverkleidung_links_innen` | 1 | LW-PLA | 106 · 48 · 14 | 2.4 | Radverkleidung (optional); Hälften verkleben, auf Achse stecken, mit Sekundenkleber am Draht sichern |
| `G9_Radverkleidung_Bug_rechts` | 1 | LW-PLA | 106 · 48 · 20 | 2.5 | Bugrad-Verkleidung (optional); Achse Ø3 geht durch Gabel und Verkleidung |
| `G9_Radverkleidung_Bug_links` | 1 | LW-PLA | 106 · 48 · 20 | 2.5 | Bugrad-Verkleidung (optional) |

## Streben

| Teil | Menge | Material | Größe x·y·z [mm] | Masse [g] | Hinweis |
|---|---:|---|---|---:|---|
| `Z1_Strebe_rechts` | 1 | PLA | 181 · 182 · 5 | 8.4 | kosmetisch; mit Epoxy an Rumpfseite und Flügelunterseite kleben |
| `Z1_Strebe_links` | 1 | PLA | 181 · 182 · 5 | 8.4 | kosmetisch; mit Epoxy an Rumpfseite und Flügelunterseite kleben |

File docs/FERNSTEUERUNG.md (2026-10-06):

# Fernsteuerung: Servos, Anlenkung, Sender

Das Modell ist komplett für den Fernsteuerbetrieb vorbereitet: Servoschächte und -böden, Ruderhörner, Gestängekanäle,
Wartungsöffnung und alle Gestängelängen sind im CAD-Modell festgelegt und **kinematisch nachgerechnet** (Servo dreht,
Gestänge bleibt gleich lang, Ruder folgt). In der 3D-Ansicht (`docs/viewer`) bewegen sich Servohebel und Gestänge mit,
wenn du die Ruder-Regler verschiebst. „Rumpf durchsichtig“ zeigt die Anlenkungen im Rumpf.

## 1. Übersicht

| Funktion | Servo | Weg zum Ruder |
|---|---|---|
| Querruder (2×) | im Flügel `W2`, Abtrieb nach unten | kurzes Gestänge zum Horn an `Q1` |
| Landeklappen (2×) | im Flügel `W1`, Abtrieb nach unten | kurzes Gestänge zum Horn an `K1` |
| Höhenruder | Rumpf `F4` **links** | Bowdenzug im Kanal, tritt links am Heck schräg aus, Horn links unten an `H2`; die rechte Ruderhälfte hängt über den 2-mm-Verbinder mit |
| Seitenruder | Rumpf `F4` **rechts** | Stab im Kanal zum **Seitenruderhebel `S4`** im Heck; `S4` klemmt auf der **Ruderwelle** (Ø 2-mm-Federstahl in der Scharnierachse, im Ruder eingeklebt) |
| Bugrad | Rumpf `F2` **links** | kurzes Gestänge zum Lenkhebel `G6` auf dem Bugfahrwerksdraht |
| Gas | Regler in der Motorhaube | – |

Warum eine Ruderwelle beim Seitenruder? Das Seitenruder beginnt erst über der Höhenflosse. Ein außen liegendes Gestänge
müsste durch die Höhenflosse laufen. Die Welle in der Scharnierachse führt die Bewegung durch die Flossenwurzel in den
Rumpf; das Gestänge bleibt komplett innen. Die Welle läuft 4,9 mm hinter dem Verbinder der Höhenruder vorbei.

## 2. Anlenkungen (aus dem Modell berechnet)

Die Tabelle wird beim Generieren aus der Geometrie neu geschrieben (`python -m cessna.build`).
„Max. Ausschlag“ = Ruderausschlag bei ±35° Servoweg mit dem angegebenen Hebel-Loch. „Servoweg-Anteil“ = wie viel von
diesen ±35° du für den Sollausschlag brauchst. Stell die Endpunkte im Sender so ein, dass der Ausschlag an der
Hinterkante stimmt (Lineal/Ausschlagslehre an der breitesten Stelle des Ruders messen).

<!-- AUTO:anlenkung -->
| Funktion | Servo | Hebel-Loch | Ruderhebel | Gestänge (Z-Bügel → Loch) | max. Ausschlag (±35° Servo) | Soll | ≈ an der Hinterkante | Servoweg-Anteil für Soll |
|---|---|---:|---:|---|---:|---:|---:|---:|
| **Querruder rechts** | Flügel W2 rechts, y = +352 mm, Abtrieb unten | 8 mm | 21 mm | **66 mm**: Stahldraht Ø1,5 mm mit Z-Bügel am Servo und Gabelkopf am Horn | ± 16° | 15° | 14 mm | ≈ 90 % |
| **Landeklappe rechts** | Flügel W1 rechts, y = +150 mm, Abtrieb unten | 10 mm | 21 mm | **68 mm**: Stahldraht Ø1,5 mm mit Z-Bügel am Servo und Gabelkopf am Horn | 0 … 35° | 35° | 32 mm | 100 % (Endlage → Endlage) |
| **Querruder links** | Flügel W2 links, y = -352 mm, Abtrieb unten | 8 mm | 21 mm | **66 mm**: Stahldraht Ø1,5 mm mit Z-Bügel am Servo und Gabelkopf am Horn | ± 16° | 15° | 14 mm | ≈ 90 % |
| **Landeklappe links** | Flügel W1 links, y = -150 mm, Abtrieb unten | 10 mm | 21 mm | **68 mm**: Stahldraht Ø1,5 mm mit Z-Bügel am Servo und Gabelkopf am Horn | 0 … 35° | 35° | 32 mm | 100 % (Endlage → Endlage) |
| **Höhenruder** | Rumpf F4 links, x = 538 mm, Abtrieb oben | 10 mm | 17 mm | **312 + 56 mm**: Bowdenzug: Außenrohr Ø3/2 mm im Kanal bis ins Austrittsloch, Stahlseele Ø1,2 mm; Z-Bügel am Servo, Gabelkopf am Horn | ± 21° | 15° | 13 mm | ≈ 70 % |
| **Seitenruder** | Rumpf F4 rechts, x = 538 mm, Abtrieb oben | 10 mm | 12 mm | **351 mm**: CFK-Stab Ø2 mm im Kanal, Enden Stahldraht Ø1,5 mm (Z-Bügel am Servo, Gabelkopf am Hebel) | ± 28° | 20° | 25 mm | ≈ 70 % |
| **Bugrad** | Rumpf F2 links, x = 190 mm, Abtrieb oben (Welle vorn) | 14 mm | 14 mm | **61 mm**: Stahldraht Ø1,2 mm mit Z-Bügeln | ± 32° | 30° | – | ≈ 95 % |
<!-- /AUTO:anlenkung -->

* **Hebel-Loch:** Abstand des Lochs am Servohebel von der Servowelle. Nimm den Standard-Hebel und bohr bei Bedarf
  ein Loch Ø 1,6 mm im passenden Abstand.
* **Gestängelänge:** Maß von Lochmitte zu Lochmitte in Neutralstellung. Beim Höhenruder gilt der erste Wert bis zum
  Knick vor dem Austrittsloch, der zweite außen bis zum Horn. Draht 10–15 mm länger abschneiden, Z-Bügel biegen,
  am Gabelkopf fein einstellen.
* **Landeklappen:** Das Servo arbeitet von Endlage zu Endlage. In Ruhe (Klappe eingefahren) steht der Hebel **35° schräg**,
  bei voll ausgefahrener Klappe 35° zur anderen Seite. So ist der ganze Servoweg für 0–35° Klappe nutzbar.

## 3. Kanalbelegung

**Mindestens 6 Kanäle** (so wie in `docs/ZUKAUFTEILE.md` bestellt):

| Kanal | Funktion | Anschluss |
|---|---|---|
| 1 | Querruder | **Y-Kabel** für beide Querruderservos. Die Servos sind gleich eingebaut; beide Ruder laufen deshalb automatisch gegenläufig. |
| 2 | Höhenruder | direkt |
| 3 | Gas | Regler (BEC versorgt den Empfänger) |
| 4 | Seitenruder + Bugrad | **Y-Kabel**. Lenkt das Bugrad falsch herum: Servo-Reverser ins Bugrad-Kabel oder Variante 8 Kanäle. |
| 5 | Landeklappen | **Y-Kabel mit Servo-Reverser** auf einer Seite. Die Klappenservos müssen **gegenläufig** drehen, weil sie spiegelbildlich anlenken. |
| 6 | frei | z. B. Flugphasen-Schalter |

**Komfort mit 8 Kanälen (empfohlen):** Jedes Flügelservo bekommt einen eigenen Kanal (Quer rechts/links, Klappe rechts/links)
und das Bugrad einen eigenen Kanal. Der Sender übernimmt dann die Richtungen und die Mischer, kein Reverser nötig.
Dazu bekommst du Querruder-Differenzierung, Klappen-Trimmung und einen eigenen Lenkausschlag fürs Bugrad.

Die **Servokabel aus dem Flügel** laufen durch die Rippen zum Langloch in der Unterseite von `W0` und von dort in die Kabine.
Verlängerungen: Querruder ca. 300 mm, Klappen ca. 150 mm. Die Heckservos reichen mit 300-mm-Verlängerungen bis zum
Empfänger. Kabel im Rumpf mit Klebeband an den Spanten fixieren, nicht über die Gestängekanäle legen.

## 4. Einbau und Neutralstellung

1. **Servos vor dem Einbau zentrieren:** Empfänger, Regler und Akku anschließen, alle Trimmungen und Subtrims auf 0.
   Bei Klappen den Klappenschalter auf „eingefahren“ stellen.
2. **Hebel aufstecken:** Bei Quer, Höhe, Seite und Bugrad den Hebel **rechtwinklig zum Gestänge** aufstecken. Er
   zeigt dann genau in die Richtung, die die 3D-Ansicht zeigt (Flügel: nach außen, Heck: zur Rumpfmitte, Bug: nach vorn).
   Bei den **Klappen** steht der Hebel in Ruhe 35° schräg (siehe oben). Kleine Restfehler gleichst du mit Subtrim aus,
   maximal ±10 %.
3. **Gestänge:** Z-Bügel ins Hebel-Loch, Gabelkopf ins Horn, Länge am Gabelkopf so einstellen, dass das Ruder neutral steht
   (Klappe: eingefahren und bündig). Gabelköpfe mit einem Stück Silikonschlauch sichern.
4. **Seitenruder:** Die Ruderwelle (Ø 2 mm, 95 mm) wird beim Verkleben der Seitenruderschalen in die Halbrinne
   eingeklebt. In der Seitenflosse liegt sie **ohne Kleber** in der Lagerrinne. Den Hebel `S4` setzt du durch die
   **Wartungsöffnung links am Heck** auf das untere Wellenende. Er zeigt nach rechts. M3-Madenschraube durch die Öffnung
   anziehen, wenn das Ruder neutral steht. Den Gabelkopf des Seitenrudergestänges ebenfalls durch die Öffnung einklipsen.
5. **Höhenruder:** Das Außenrohr des Bowdenzugs (Ø 3/2 mm) läuft im Kanal von `F4` bis ins schräge Austrittsloch links am
   Heck. Dort bündig abschneiden und einkleben. Die Stahlseele läuft innen.
6. **Bugrad:** Lenkhebel `G6` so auf den Draht klemmen, dass das Rad bei neutralem Seitenruder geradeaus steht.
   Das Anlenkloch ist **senkrecht**, also Z-Bügel von oben einhängen.

## 5. Senderprogrammierung

| Funktion | Ausschlag | Dual Rate „niedrig“ | Expo |
|---|---:|---:|---:|
| Querruder | ± 15° | ± 10° | 30 % |
| Höhenruder | ± 15° | ± 10° | 25 % |
| Seitenruder | ± 20° | ± 15° | 20 % |
| Bugrad | ± 30° (bei Y-Kabel folgt es dem Seitenruder, dann ca. ± 25°) | – | – |
| Landeklappen | 0° / 15° (Start) / 35° (Landung) über 3-Stufen-Schalter, Servogeschwindigkeit 1–2 s | – | – |

* **Klappen → Höhe:** Beim Ausfahren der Klappen nimmt das Modell meist die Nase hoch. Mischer Klappe → Höhenruder mit
  2–3° **tief** bei 35° Klappe als Startwert, im Flug nachtrimmen.
* **Querruder-Differenzierung** (nur mit 2 Kanälen): 30–40 % (mehr nach oben als nach unten), das mindert das negative Wendemoment.
* **Gas:** Motor-Aus-Schalter (Throttle Cut) einrichten. Den Regler vor dem ersten Lauf auf den Gasweg einlernen.
* **Failsafe:** Gas auf **Motor aus**, Ruder neutral, Klappen eingefahren. Prüfen: Sender ausschalten, der Motor muss stoppen.
* **Drehrichtungen prüfen** (von hinten gesehen):
  * Knüppel rechts: rechtes Querruder hoch, linkes runter.
  * Knüppel gezogen: Höhenruder hoch.
  * Seite rechts: Ruderhinterkante nach rechts, Bugrad lenkt nach rechts.
  * Klappenschalter: beide Klappen nach unten.

## 6. Vor dem Erstflug

1. **Ruder-Check:** Alle Ruder laufen ohne Klemmen über den vollen Weg. Die Servos dürfen in den Endlagen nicht brummen,
   sonst den Endpunkt reduzieren.
2. **Spiel:** Ruder an der Hinterkante leicht bewegen; mehr als ca. 1 mm Spiel → Gabelkopf/Z-Bügel nacharbeiten.
3. **Reichweitentest** im Reichweitentest-Modus des Senders, einmal mit laufendem Motor.
4. **Schwerpunkt** nach `docs/BAUANLEITUNG.md` Abschnitt 7 einstellen. Die Lage von Akku und Empfänger ist im Modell
   berücksichtigt: Akku x ≈ 170–285 mm, Empfänger rechts in der Kabine.
5. **Empfängerantennen** 90° zueinander, weg von Regler, Motor- und Akkukabeln.

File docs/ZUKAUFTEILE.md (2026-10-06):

# Zukaufteile (Elektronik, Kohlefaser, Draht, Kleinteile)

Alle Angaben passen zu den Maßen der gedruckten Teile. Gewichte sind Richtwerte; sie gehen in die
Schwerpunktrechnung ein (`cessna/params.py`, Abschnitt `BOUGHT_PARTS`).

## Antrieb

| Teil | Empfehlung | Menge |
|---|---|---:|
| Außenläufer | Klasse 28xx, ca. 1000–1100 kV, Ø 28 mm, ca. 70–80 g, Befestigung 16/19-mm-Kreuz (M3) | 1 |
| Regler | 30 A (besser 40 A), BEC ≥ 3 A | 1 |
| Luftschraube | 10×6″ (z. B. APC 10×6 E), 2 Blatt; **Bodenfreiheit nur ca. 23 mm** (Wellenhöhe 150 mm) → auf rauem Gras besser 9×6″ (36 mm) | 1 |
| Propelleradapter | mit Mitnehmerscheibe, Welle passend zum Motor (3,17 / 4 / 5 mm) | 1 |
| Akku | LiPo 3S 2200 mAh, ≥ 25C, **max. 115 × 35 × 26 mm**, ca. 190 g | 1 |

Richtwerte (nicht geflogen!): 3S + 1000 kV + 10×6″ → ca. 22–26 A, 250–300 W, Standschub ca. 800–950 g,
Schub/Gewicht ≈ 0,5–0,6.

## Funkanlage

| Teil | Hinweis | Menge |
|---|---|---:|
| Empfänger | mind. 6 Kanäle (Quer, Höhe, Gas, Seite+Bugrad, Klappen); **8 Kanäle empfohlen** (jedes Flügelservo und das Bugrad einzeln). Kanalplan: `docs/FERNSTEUERUNG.md` | 1 |
| Servos 9 g | Mikroservos mit Metallgetriebe für Seite/Höhe empfohlen; **Abmessungen 23 × 12,4 × 22,8 mm, Flansch 32,5 mm** | 7 |
| Servo-Verlängerung | ca. 300 mm für Querruder und Heckservos, ca. 150 mm für die Klappen (→ Kabine) | 6 |
| Y-Kabel | Querruder (bei 6 Kanälen; die Ruder laufen ohne Reverser gegenläufig) | 1 |
| Y-Kabel + Servo-Reverser | Landeklappen (bei 6 Kanälen; die Klappenservos müssen gegenläufig drehen) | 1 |
| Y-Kabel | Bugradlenkung auf dem Seitenruder-Kanal (bei 6 Kanälen; ggf. Reverser für die Lenkrichtung) | 1 |

Servo-Verteilung: 2× Querruder und 2× Landeklappe (im Flügel, Abtrieb nach unten), 1× Höhenruder (Rumpf links, Heck),
1× Seitenruder (Rumpf rechts, Heck), 1× Bugradlenkung (Bug links).

## Kohlefaser / Draht (Zuschnitt in mm)

| Teil | Maß | Menge | Verwendung |
|---|---|---:|---|
| CFK-Rohr 10/8 mm | **660** | 2 | Flügelholm (links/rechts) |
| CFK-Stab Ø 7,8 mm (oder 8 mm abschleifen) | 200 | 1 | Flächenverbinder in der Mitte |
| CFK-Stab Ø 4 mm | 395 | 1 | Holm Höhenflosse (durch beide Hälften) |
| CFK-Stab Ø 2 mm | 370 | 1 | Höhenruder-Verbindung (durch beide Nasen) |
| Bowdenzug: Außenrohr Ø 3/2 mm + Stahlseele Ø 1,2 mm | Rohr ca. 330, Seele ca. 400 | 1 | Höhenruder (Kanal links, schräger Austritt am Heck) |
| CFK-Stab Ø 2 mm | ca. 320 | 1 | Seitenrudergestänge im Rumpf (Servo → Hebel `S4`), Enden: |
| Stahldraht Ø 1,5 mm | je ca. 40 | 2 | Enden des Seitenrudergestänges (Z-Bügel / Gabelkopf, mit Schrumpfschlauch und Sekundenkleber auf den CFK-Stab) |
| **Federstahldraht Ø 2 mm** | **95** | 1 | **Ruderwelle Seitenruder** (im Ruder eingeklebt, in der Flosse gelagert) |
| Stahldraht Ø 1,5 mm | je ca. 80 | 4 | Gestänge Querruder (66 mm) und Landeklappen (68 mm), Z-Bügel + Gabelkopf |
| Stahldraht Ø 1,2 mm | ca. 75 | 1 | Bugradlenkung (Servo → Lenkhebel, 61 mm, zwei Z-Bügel) |
| **Federstahldraht Ø 4 mm** | **ca. 390** | 1 | Hauptfahrwerk, nach Biegeschablone `docs/fahrwerk_biegeschablone.pdf` |
| Federstahldraht Ø 3 mm | ca. 56 | 1 | Bugfahrwerk (gerade, in die Gabel geklebt) |
| Stahlstab Ø 3 mm | ca. 44 | 1 | Bugrad-Achse (durch Gabel und Radverkleidung) |
| Stahlstab Ø 4 mm | ca. 35 je | 2 | Radachsen = Enden des Fahrwerksdrahts (kein extra Teil) |
| Stellringe Ø 3 / Ø 4 mm | | je 4 | Räder sichern |

## Schrauben, Kleinteile

| Teil | Menge | Verwendung |
|---|---:|---|
| M3 × 20 Blechschraube (Linsenkopf) + Unterlegscheibe | 4 | Flügel auf Rumpf (Dome in W0, Gewinde in den Spantbalken) |
| M3 × 8 Zylinderschraube | 4 | Motor an Motorbock (Kreuz 16 oder 19 mm) |
| M3 × 10 Zylinderschraube + Mutter | 4 | Motorbock an Brandschott |
| M2,5 × 10 Blechschraube | 4 | Motorhaube am Brandschott |
| M2,5 × 10 Blechschraube | 4 | Spinnerkegel an Spinnerplatte |
| M3 × 12 Blechschraube | 2 | Hauptfahrwerks-Klemme |
| M3 × 4 Madenschraube | 2 | Lenkhebel `G6` auf dem Bugfahrwerksdraht, Seitenruderhebel `S4` auf der Ruderwelle |
| M2 × 8 Blechschraube | 14 | 7 Servos (je 2; im Flügel zusätzlich Heißkleber) |
| Gabelköpfe M2 + Gewindestück zum Einlöten/Kleben | 6 | Querruder, Klappen, Höhenruder, Seitenruder (Hebel `S4`) |
| Servohebel (Standard, Löcher 8–14 mm) | 7 | meist beim Servo dabei; fehlendes Loch Ø 1,6 mm nachbohren |
| Silikonschlauch 3 mm | 10 cm | Gabelköpfe sichern |
| Scharnierband / transparentes Gewebeband 25 mm | ca. 3 m | Ruderscharniere (beidseitig) |
| Epoxy 30 min, dünnflüssiger Sekundenkleber + Aktivator | | Verklebung (siehe Bauanleitung) |
| Klett / Akkugurt | | Akku, Regler, Empfänger |

## Optional

* Räder: statt gedruckter Naben/Reifen Schaumgummi- oder Gummiräder Ø 55 mm, Achse 4 mm (Haupt) / 3 mm (Bug).
* Trimmblei 20–60 g (Klett) im Bug, falls der Schwerpunkt nach dem Bau zu weit hinten liegt.
* Lack: Acryl-/Sprühfarbe für LW-PLA (Grundierung dünn auftragen!); Fenster nach den Gravuren abkleben.

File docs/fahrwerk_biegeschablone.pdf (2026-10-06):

Rumpfwand Hauptfahrwerk: Federstahldraht Ø4 mm - rechte Hälfte im Maßstab 1:1 (A4 quer ohne Skalierung drucken), Draht gesamt ca. 391 mm, links spiegelbildlich

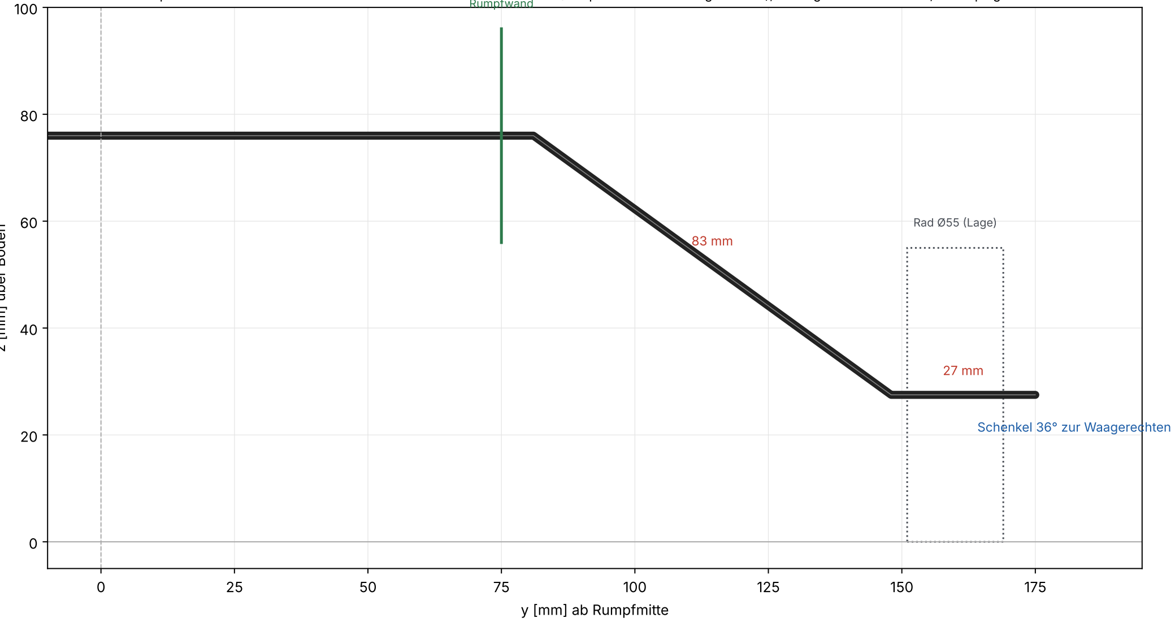
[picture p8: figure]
y [mm] ab Rumpfmitte; z [mm] über Boden; Rad Ø55 (Lage); Schenkel 36° zur Waagerechten

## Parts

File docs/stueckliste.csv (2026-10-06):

Teil | Gruppe | Anzahl | Material | Druckgroesse x [mm] | y [mm] | z [mm] | Masse je Teil [g] | Hinweis
W0_Mittelstueck | Flügel | 1 | LW-PLA | 199.8 | 160.0 | 23.8 | 57.5 | 4 Schraubendome für M3, Kabelaustritt unten
W1_rechts | Flügel | 1 | LW-PLA | 199.8 | 202.5 | 23.8 | 54.6 | mit Servoschacht für das Klappenservo
W1_links | Flügel | 1 | LW-PLA | 199.8 | 202.5 | 23.8 | 54.6 | mit Servoschacht für das Klappenservo
K1_Landeklappe_rechts | Querruder | 1 | LW-PLA | 64.1 | 191.3 | 14.4 | 30.5 | Landeklappe 0..35° nach unten; Horn-Schlitz an der Unterseite
K1_Landeklappe_links | Querruder | 1 | LW-PLA | 64.1 | 191.3 | 14.4 | 30.5 | Landeklappe 0..35° nach unten; Horn-Schlitz an der Unterseite
W2_rechts | Flügel | 1 | LW-PLA | 200.0 | 204.1 | 24.0 | 52.6 | mit Servoschacht für 9-g-Servo (Querruder)
W2_links | Flügel | 1 | LW-PLA | 200.0 | 204.1 | 24.0 | 52.6 | mit Servoschacht für 9-g-Servo (Querruder)
Q1_Querruder_innen_rechts | Querruder | 1 | LW-PLA | 77.6 | 154.1 | 14.0 | 21.5 | Horn-Schlitz an der Unterseite; mit Q2 zu einem Ruder verkleben
Q1_Querruder_innen_links | Querruder | 1 | LW-PLA | 77.6 | 154.1 | 14.0 | 21.5 | Horn-Schlitz an der Unterseite; mit Q2 zu einem Ruder verkleben
W3_rechts | Flügel | 1 | LW-PLA | 147.0 | 203.1 | 20.4 | 41.6 | mit abgerundetem Randbogen
W3_links | Flügel | 1 | LW-PLA | 147.0 | 203.1 | 20.4 | 41.6 | mit abgerundetem Randbogen
Q2_Querruder_aussen_rechts | Querruder | 1 | LW-PLA | 71.1 | 164.2 | 12.4 | 18.3
Q2_Querruder_aussen_links | Querruder | 1 | LW-PLA | 71.1 | 164.2 | 12.4 | 18.3
H1_Hoehenflosse_rechts_oben | Leitwerk | 1 | LW-PLA | 103.9 | 205.0 | 6.5 | 7.9 | CFK-Stab Ø4 als Holm durch beide Hälften
H1_Hoehenflosse_rechts_unten | Leitwerk | 1 | LW-PLA | 103.9 | 204.9 | 6.5 | 7.9 | CFK-Stab Ø4 als Holm durch beide Hälften
H1_Hoehenflosse_links_oben | Leitwerk | 1 | LW-PLA | 103.9 | 205.0 | 6.5 | 7.9 | CFK-Stab Ø4 als Holm durch beide Hälften
H1_Hoehenflosse_links_unten | Leitwerk | 1 | LW-PLA | 103.9 | 204.9 | 6.5 | 7.9 | CFK-Stab Ø4 als Holm durch beide Hälften
H2_Hoehenruder_rechts_oben | Leitwerk | 1 | LW-PLA | 72.0 | 177.1 | 5.3 | 8.0 | 2-mm-CFK-Stab verbindet beide Hälften; Horn nur an einer Seite
H2_Hoehenruder_rechts_unten | Leitwerk | 1 | LW-PLA | 72.0 | 177.1 | 5.2 | 8.0 | 2-mm-CFK-Stab verbindet beide Hälften; Horn nur an einer Seite
H2_Hoehenruder_links_oben | Leitwerk | 1 | LW-PLA | 72.0 | 177.1 | 5.3 | 8.0 | 2-mm-CFK-Stab verbindet beide Hälften; Horn nur an einer Seite
H2_Hoehenruder_links_unten | Leitwerk | 1 | LW-PLA | 72.0 | 177.1 | 5.2 | 8.0 | 2-mm-CFK-Stab verbindet beide Hälften; Horn nur an einer Seite
S1_Seitenflosse_oben | Leitwerk | 1 | LW-PLA | 205.0 | 175.0 | 9.3 | 10.3 | unterste 15 mm stecken im Heck (Schlitz im Rumpf)
S1_Seitenflosse_unten | Leitwerk | 1 | LW-PLA | 205.0 | 175.0 | 9.3 | 10.3 | unterste 15 mm stecken im Heck (Schlitz im Rumpf)
S2_Seitenruder_oben | Leitwerk | 1 | LW-PLA | 81.8 | 116.2 | 6.7 | 6.9
S2_Seitenruder_unten | Leitwerk | 1 | LW-PLA | 81.8 | 116.2 | 6.7 | 6.9
S4_Seitenruderhebel | Leitwerk | 1 | PETG | 20.5 | 10.0 | 8.0 | 1.1 | klemmt mit M3-Madenschraube auf der Ø2-Ruderwelle; Zugang durch die Wartungsöffnung links im Heck
Ruderhorn | Kleinteile | 5 | PETG | 14.0 | 18.5 | 1.8 | 0.3 | je 1x Querruder links/rechts, Landeklappe links/rechts, Höhenruder (links unten)
F1_Motorhaube_rechts | Rumpf | 1 | LW-PLA | 130.7 | 123.0 | 69.7 | 23.2
F1_Motorhaube_links | Rumpf | 1 | LW-PLA | 130.7 | 123.0 | 69.7 | 23.2
F2_Bug_rechts | Rumpf | 1 | LW-PLA | 194.9 | 174.0 | 75.0 | 54.3 | mit Steckmuffe nach hinten
F2_Bug_links | Rumpf | 1 | LW-PLA | 194.9 | 174.0 | 75.0 | 55.1 | mit Steckmuffe nach hinten
F3_Kabine_rechts | Rumpf | 1 | LW-PLA | 198.0 | 174.0 | 75.0 | 57.5 | mit Steckmuffe nach hinten
F3_Kabine_links | Rumpf | 1 | LW-PLA | 198.0 | 174.0 | 75.0 | 57.5 | mit Steckmuffe nach hinten
F4_Rumpfmitte_rechts | Rumpf | 1 | LW-PLA | 177.6 | 174.0 | 74.0 | 29.0 | mit Steckmuffe nach hinten
F4_Rumpfmitte_links | Rumpf | 1 | LW-PLA | 177.6 | 174.0 | 74.0 | 29.0 | mit Steckmuffe nach hinten
F5_Heckkonus_rechts | Rumpf | 1 | LW-PLA | 183.0 | 86.8 | 48.5 | 15.4 | mit Steckmuffe nach hinten
F5_Heckkonus_links | Rumpf | 1 | LW-PLA | 183.0 | 86.8 | 48.5 | 15.4 | mit Steckmuffe nach hinten
F6_Heck_rechts | Rumpf | 1 | LW-PLA | 151.4 | 45.7 | 23.9 | 7.3
F6_Heck_links | Rumpf | 1 | LW-PLA | 151.4 | 45.7 | 23.9 | 7.1
S3_Rueckenflosse | Leitwerk | 1 | LW-PLA | 111.6 | 28.3 | 5.0 | 2.3 | flach drucken; auf den Rumpfrücken (F5) und an die Vorderkante der Seitenflosse kleben
P1_Motorbock | Antrieb | 1 | PETG | 52.0 | 52.0 | 93.0 | 15.3 | Motor vorn mit 4x M3 anschrauben, hinten mit 4x M3 an den Brandschott; Hitze -> PETG
P2_Spinner | Antrieb | 1 | PLA | 48.2 | 48.2 | 45.0 | 9.7 | offene Seite nach unten drucken; 4x M2.5x10 Blechschrauben in die Domen
P3_Spinnerplatte | Antrieb | 1 | PETG | 50.0 | 50.0 | 3.0 | 7.2 | mit Mitnehmer/Propelleradapter verschrauben
G1_Reifen | Fahrwerk | 3 | TPU | 55.0 | 55.0 | 18.0 | 3.9 | TPU 95A, 2 Hauptreifen + 1 Bugreifen (1-2 mm Wand reicht)
G2_Radnabe | Fahrwerk | 3 | PLA | 38.0 | 38.0 | 16.0 | 2.1 | Reifen aufkleben (Sekundenkleber); Achsbohrung 4,2 mm (Haupt), Bugrad auf 3 mm aufbohren
G3_Hauptfahrwerk_Klemme_unten | Fahrwerk | 1 | PETG | 30.0 | 52.0 | 8.8 | 10.1 | auf den Rumpfboden kleben; Draht 4 mm Federstahl
G4_Hauptfahrwerk_Klemme_oben | Fahrwerk | 1 | PETG | 30.0 | 52.0 | 6.0 | 6.5 | 2x M3x12 Blechschrauben in die Bohrungen des unteren Blocks
G5_Bugfahrwerkslager | Fahrwerk | 1 | PETG | 27.7 | 26.0 | 34.7 | 17.4 | auf Rumpfboden und Brandschott kleben; 3-mm-Federstahl, Messingrohr 4/3 optional
G6_Lenkhebel | Fahrwerk | 1 | PETG | 22.0 | 10.0 | 9.0 | 1.2 | M3-Madenschraube klemmt auf dem 3-mm-Bugfahrwerksdraht
G7_Bugradgabel | Fahrwerk | 1 | PETG | 16.0 | 29.5 | 51.5 | 11.8 | Bruecke liegt auf dem Druckbett; 3-mm-Draht einkleben, Achse 3-mm-Stab (Stellringe)
G8_Radverkleidung_rechts_aussen | Fahrwerk | 1 | LW-PLA | 106.0 | 48.5 | 14.5 | 2.4 | Radverkleidung (optional); Hälften verkleben, auf Achse stecken, mit Sekundenkleber am Draht sichern
G8_Radverkleidung_rechts_innen | Fahrwerk | 1 | LW-PLA | 106.0 | 48.5 | 14.5 | 2.4 | Radverkleidung (optional); Hälften verkleben, auf Achse stecken, mit Sekundenkleber am Draht sichern
G8_Radverkleidung_links_aussen | Fahrwerk | 1 | LW-PLA | 106.0 | 48.5 | 14.5 | 2.4 | Radverkleidung (optional); Hälften verkleben, auf Achse stecken, mit Sekundenkleber am Draht sichern
G8_Radverkleidung_links_innen | Fahrwerk | 1 | LW-PLA | 106.0 | 48.5 | 14.5 | 2.4 | Radverkleidung (optional); Hälften verkleben, auf Achse stecken, mit Sekundenkleber am Draht sichern
G9_Radverkleidung_Bug_rechts | Fahrwerk | 1 | LW-PLA | 106.0 | 48.4 | 20.0 | 2.5 | Bugrad-Verkleidung (optional); Achse Ø3 geht durch Gabel und Verkleidung
G9_Radverkleidung_Bug_links | Fahrwerk | 1 | LW-PLA | 106.0 | 48.4 | 20.0 | 2.5 | Bugrad-Verkleidung (optional)
Z1_Strebe_rechts | Streben | 1 | PLA | 180.6 | 182.0 | 5.0 | 8.4 | kosmetisch; mit Epoxy an Rumpfseite und Flügelunterseite kleben
Z1_Strebe_links | Streben | 1 | PLA | 180.6 | 182.0 | 5.0 | 8.4 | kosmetisch; mit Epoxy an Rumpfseite und Flügelunterseite kleben

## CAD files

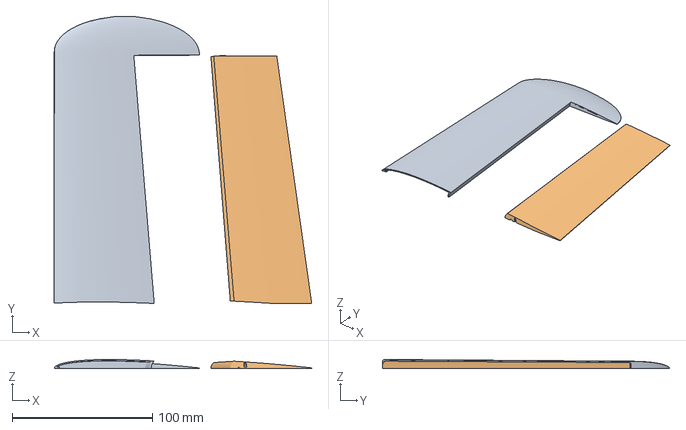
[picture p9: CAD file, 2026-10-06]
druckplatten/14_LW-PLA_Leitwerk_H1+H2_rechts_oben.3mf
183.9 x 205.0 x 6.47 mm
H1_Hoehenflosse_rechts_oben
H2_Hoehenruder_rechts_oben

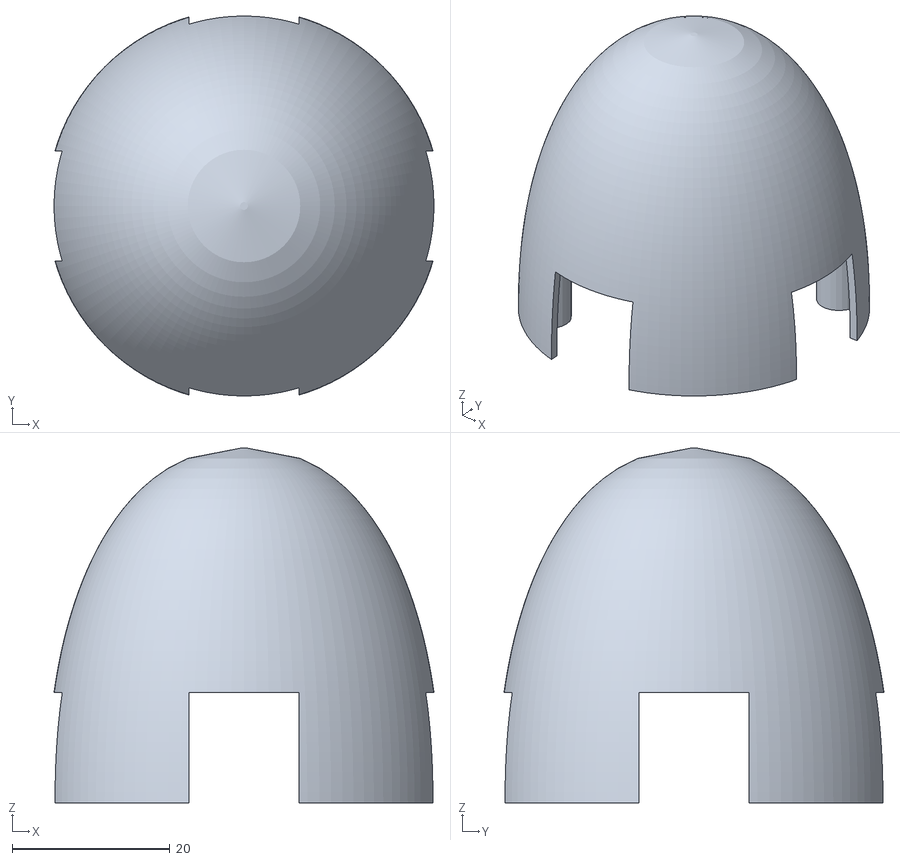
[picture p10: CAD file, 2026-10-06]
stl/Antrieb/P2_Spinner.stl
48.2 x 48.2 x 45.0

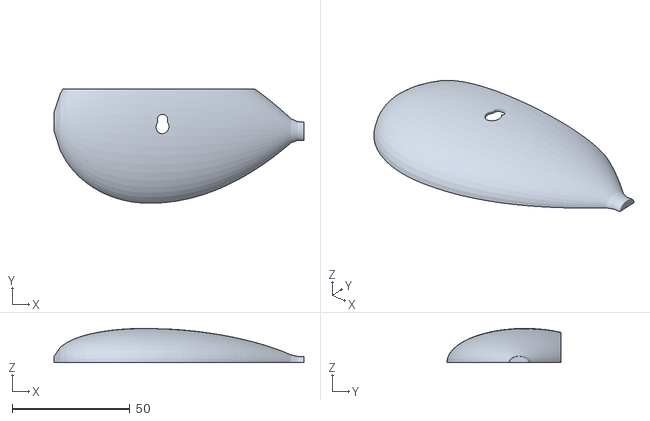
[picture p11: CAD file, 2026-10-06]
stl/Fahrwerk/G8_Radverkleidung_links_innen.stl
106.0 x 48.5 x 14.5

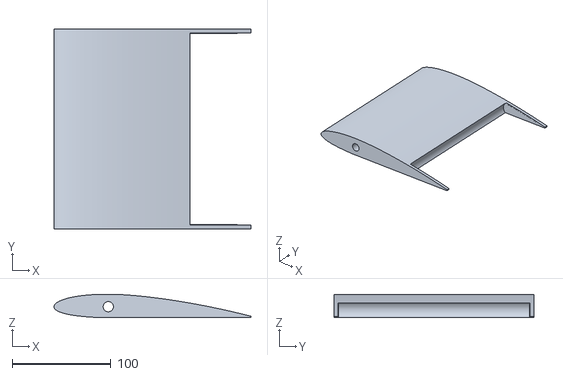
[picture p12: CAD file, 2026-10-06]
stl/Fluegel/W1_rechts.stl
199.8 x 202.5 x 23.8

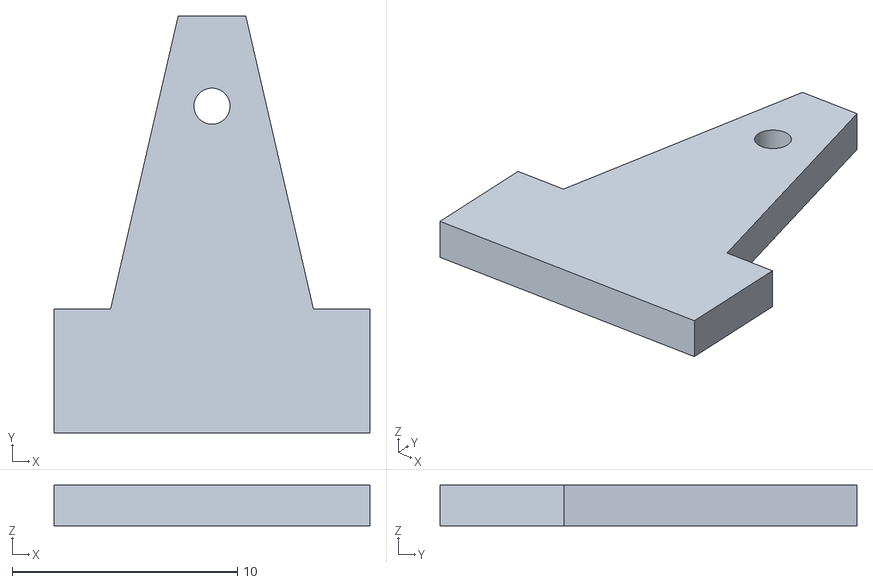
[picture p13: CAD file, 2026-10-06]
stl/Kleinteile/Ruderhorn.stl
14.0 x 18.5 x 1.80

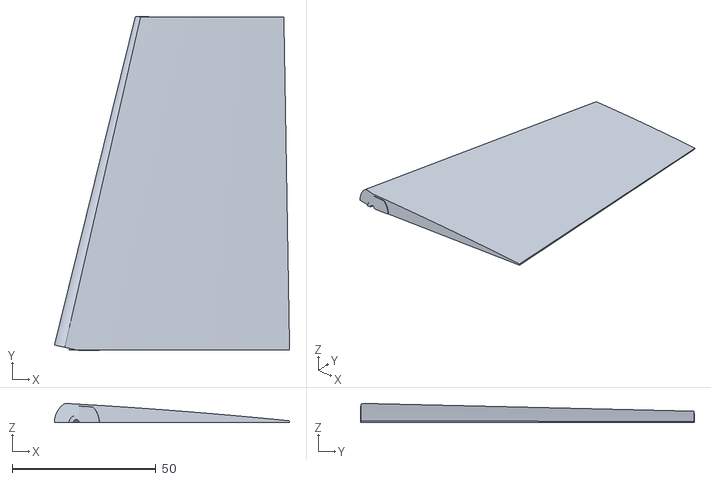
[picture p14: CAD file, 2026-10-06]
stl/Leitwerk/S2_Seitenruder_oben.stl
81.8 x 116.2 x 6.68

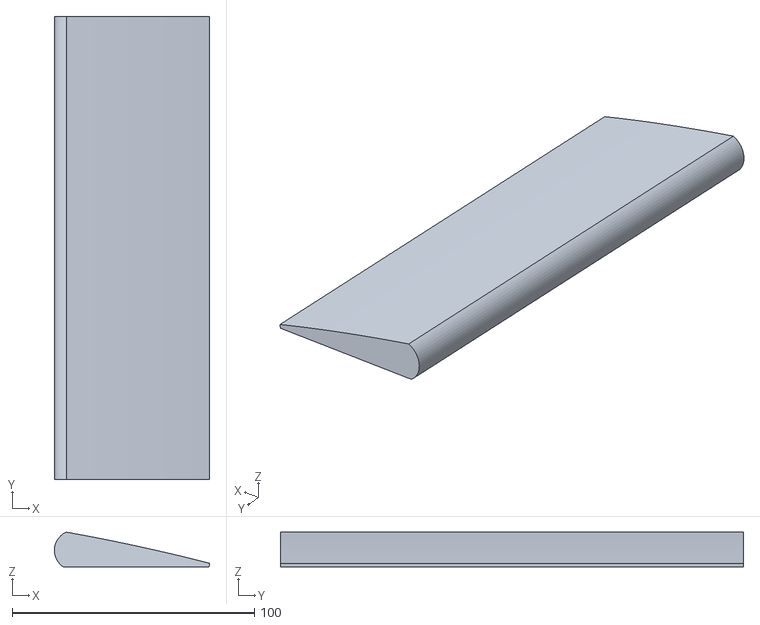
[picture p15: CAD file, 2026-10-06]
stl/Querruder/K1_Landeklappe_rechts.stl
64.1 x 191.3 x 14.4

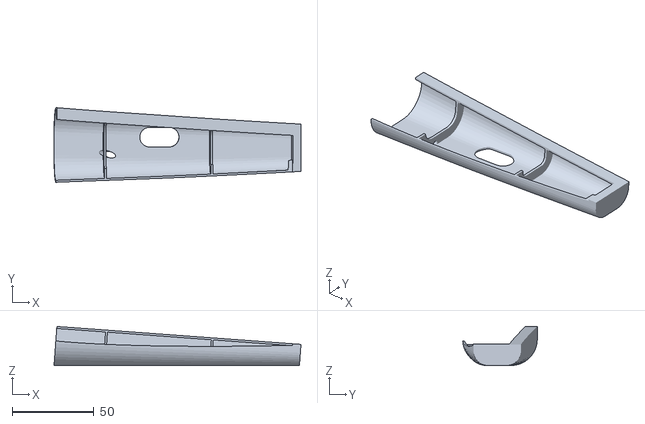
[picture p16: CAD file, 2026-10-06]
stl/Rumpf/F6_Heck_links.stl
151.4 x 45.7 x 23.9

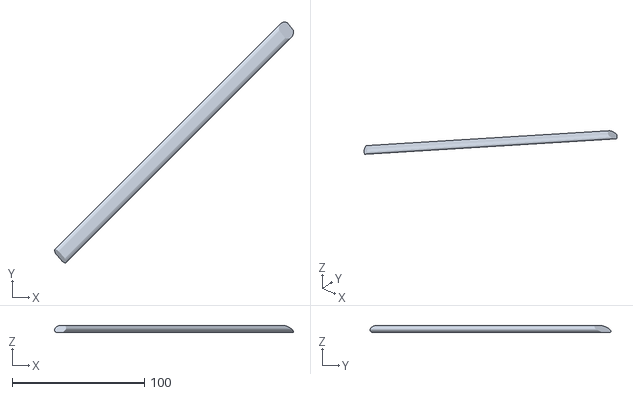
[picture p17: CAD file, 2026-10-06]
stl/Streben/Z1_Strebe_links.stl
180.6 x 182.0 x 5.00

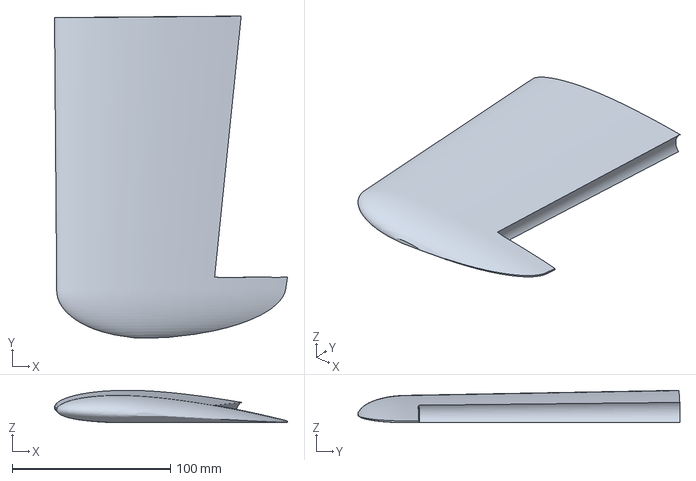
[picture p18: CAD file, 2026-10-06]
druckplatten/06_LW-PLA_Fluegel_W3_links.3mf
147.0 x 203.1 x 20.4 mm

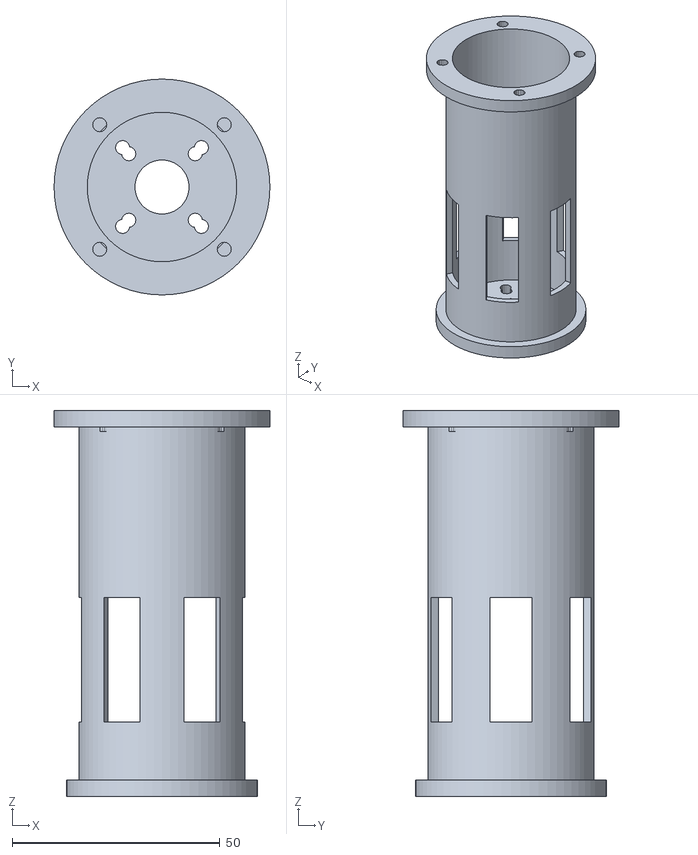
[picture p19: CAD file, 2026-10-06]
stl/Antrieb/P1_Motorbock.stl
52.0 x 52.0 x 93.0

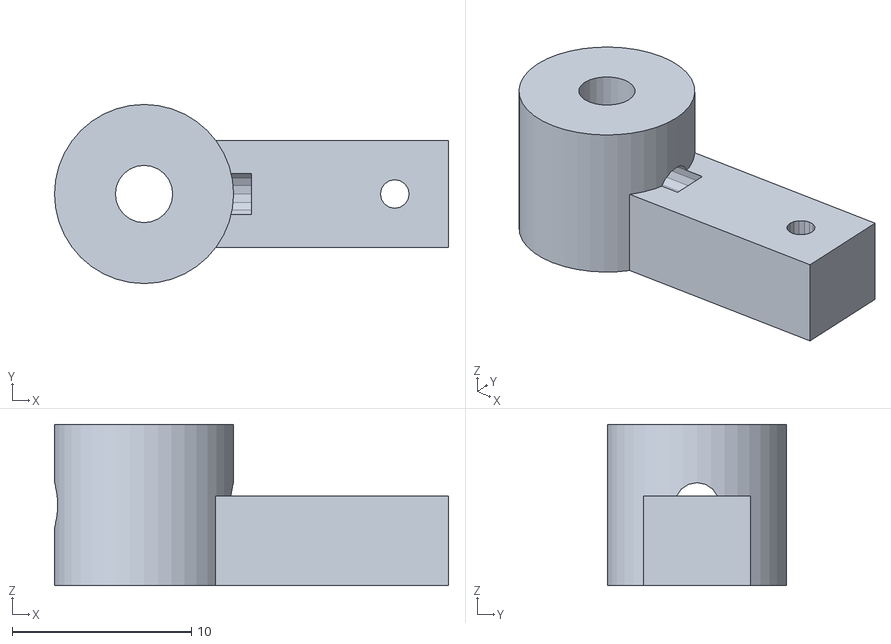
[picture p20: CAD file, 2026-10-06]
stl/Fahrwerk/G6_Lenkhebel.stl
22.0 x 10.0 x 9.00

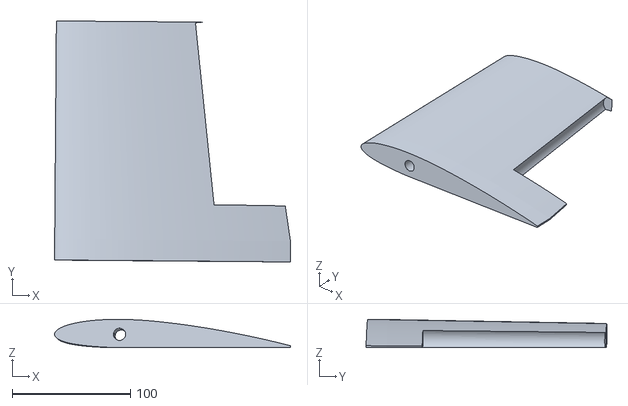
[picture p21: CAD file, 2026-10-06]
stl/Fluegel/W2_rechts.stl
200.0 x 204.1 x 24.0

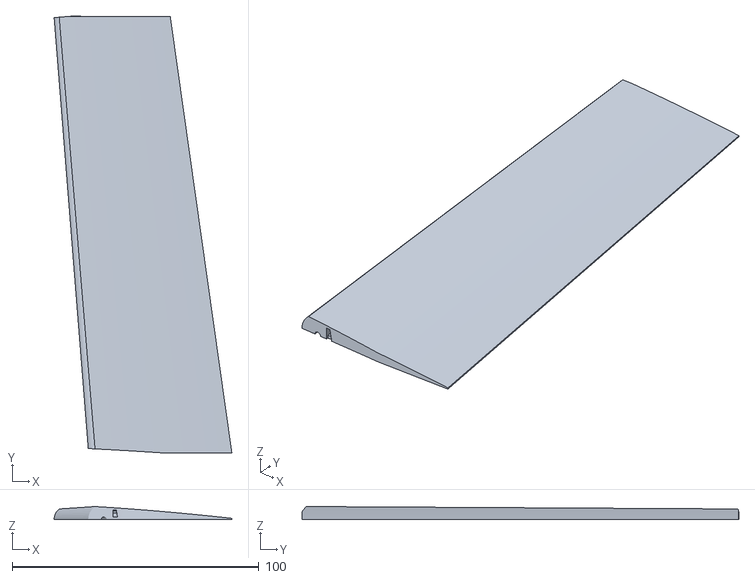
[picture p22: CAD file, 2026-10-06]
stl/Leitwerk/H2_Hoehenruder_rechts_oben.stl
72.0 x 177.1 x 5.25

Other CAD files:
stl/Querruder/K1_Landeklappe_links.stl
stl/Rumpf/F5_Heckkonus_links.stl
stl/Streben/Z1_Strebe_rechts.stl
druckplatten/22_LW-PLA_Rumpf_F4_Rumpfmitte_links.3mf
druckplatten/01_LW-PLA_Fluegel_W0_Mittelstueck.3mf
druckplatten/02_LW-PLA_Fluegel_W2_links.3mf
druckplatten/03_LW-PLA_Fluegel_W2_rechts.3mf
druckplatten/04_LW-PLA_Fluegel_W1_links.3mf
druckplatten/05_LW-PLA_Fluegel_W1_rechts.3mf
druckplatten/07_LW-PLA_Fluegel_W3_rechts.3mf
druckplatten/08_LW-PLA_Fluegel_K1_Landeklappe_links+rechts.3mf
druckplatten/09_LW-PLA_Fluegel_Q1_Querruder_innen_links+rechts.3mf
druckplatten/10_LW-PLA_Fluegel_Q2_Querruder_aussen_links+rechts.3mf
druckplatten/11_LW-PLA_Leitwerk_S1+S3.3mf
druckplatten/12_LW-PLA_Leitwerk_S1_Seitenflosse_unten.3mf
druckplatten/13_LW-PLA_Leitwerk_H1+H2_links_oben.3mf
druckplatten/15_LW-PLA_Leitwerk_H1+H2_links_unten.3mf
druckplatten/16_LW-PLA_Leitwerk_H1+H2_rechts_unten.3mf
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

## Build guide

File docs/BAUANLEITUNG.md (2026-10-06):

# Bauanleitung

Reihenfolge: **Flügel → Leitwerk → Rumpf → Antrieb → Fahrwerk → Elektronik/Gestänge → Endmontage → Schwerpunkt**.
Alles zu Servos, Hebel-Löchern, Gestängelängen, Kanalbelegung und Senderprogrammierung steht in
**[`docs/FERNSTEUERUNG.md`](FERNSTEUERUNG.md)**.
Teilenamen entsprechen den STL-Dateien (`stl/…`) und der Druckliste (`docs/DRUCKLISTE.md`).

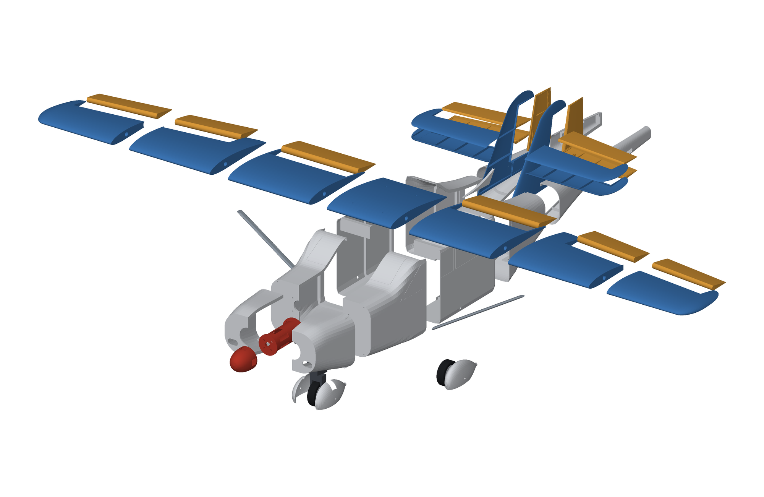
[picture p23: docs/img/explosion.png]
Explosionszeichnung


**Werkzeug/Kleber:** Epoxy 30 min (CFK, tragende Verbindungen), dünner + mittelviskoser Sekundenkleber mit Aktivator
(LW-PLA-Verklebungen; „schaumverträglich" ist unkritisch), feines Schleifpapier (240), Lineal/Richtbrett,
Messer, Schraubendreher, Seitenschneider, Biegezange für Federstahl, Gewebeband.

---

## 1. Flügel (einteilig, 1375 mm)

Teile: `W0` (Mitte), `W1`/`W2`/`W3` je links/rechts, 2× CFK-Rohr 10/8 × 660 mm, 1× Verbinderstab Ø 7,8 × 200 mm,
`Q1`/`Q2` Querruder.

1. **Trockenmontage.** Stecke beide CFK-Rohre durch die Holmbohrungen (Ø 10,4 mm, in den Rippen) von `W3` bis `W0`.
   Die Rohre reichen von der Flügelmitte bis in den Randbogen (660 mm). In der Mitte stecken die beiden Rohrenden
   auf dem **Verbinderstab** (je 100 mm). Alles muss ohne Gewalt sitzen; ggf. Bohrungen mit einer Rundfeile oder
   einer 10-mm-Reibahle kalibrieren.
2. **Verkleben.** Epoxy dünn in die Holmhülsen jedes Abschnitts geben (nicht ins ganze Rohr!), Abschnitte auf die Rohre
   schieben und die Stirnflächen (umlaufende Haut + Endrippen, 3 mm Rand) mit Sekundenkleber/Epoxy verbinden. Flügel
   dabei flach auf einem Richtbrett ausrichten (Vorderkante gerade!). Reihenfolge: `W0` + `W1` + `W2` + `W3` je Seite.
3. **Servos.** In `W2` sitzt der Servoschacht (Lage y = ±352 mm). 9-g-Servo mit **Abtrieb nach unten** einsetzen: der
   Flansch liegt auf dem Rand des Schachts, Servo mit Heißkleber sichern. Kabel durch die Kerbe im Schacht und die
   Rippenlöcher (hinter dem Holm) nach innen führen. Das Kabel tritt in der Flügelmitte durch das **Langloch in der
   Unterseite von `W0`** in die Kabine aus.
4. **Querruder.** `Q1` (innen) und `Q2` (außen) liegen mit ihrem Stoß bei y = 485 mm aneinander; mit Sekundenkleber (dünn, Stirnflächen
   plus Endrippen) zu **einem** Ruder verbinden (je Seite); optional 3-mm-CFK-Stab als Dorn (Löcher von Hand bohren). Ruderhorn (`Ruderhorn`)
   in den Schlitz an der Unterseite von `Q1` kleben (Epoxy). Scharniere: transparentes Band **oben und unten** über die
   1,6-mm-Fuge kleben; Ruder in der Mitte „biegen“, bis es leicht schwingt. Die Konstruktion lässt ±30° Ausschlag
   zu (virtuell geprüft).
5. **Anlenkung.** Servohebel zeigt nach außen (rechtwinklig zum Gestänge), Loch **8 mm** von der Welle. Gestänge Ø 1,5 mm
   (66 mm Lochmitte–Lochmitte) mit Z-Bügel am Servo und Gabelkopf am Horn. Maße: `docs/FERNSTEUERUNG.md`.
6. **Landeklappen.** `W1` hat einen zweiten Servoschacht (y = ±150 mm). Klappe `K1` genauso wie das Querruder mit
   Gewebeband anschlagen, Horn in den Schlitz an der Unterseite (y = ±172 mm). Hebel-Loch **10 mm**, Gestänge 68 mm.
   Das Servo fährt von Endlage zu Endlage: Klappe eingefahren = Hebel 35° schräg, Klappe 35° unten = Hebel 35° zur
   anderen Seite. Die beiden Klappenservos drehen **gegenläufig** (Servo-Reverser oder eigener Kanal).

Optional: Flügel vor dem Verkleben auf Verzug prüfen (beide Spitzen müssen auf dem Richtbrett aufliegen).

## 2. Leitwerk

Teile: `H1` Höhenflosse (rechts/links, je oben+unten), `H2` Höhenruder (rechts/links, je oben+unten),
`S1` Seitenflosse (oben/unten), `S2` Seitenruder (oben/unten), `S4` Seitenruderhebel, CFK Ø 4 × 395, CFK Ø 2 × 370,
Federstahl Ø 2 × 95 (Ruderwelle), 1× Ruderhorn.

1. **Schalen verkleben.** Je zwei Schalen (oben/unten) an der Naht mit dünnem Sekundenkleber; der Flansch
   (3 mm breit) und die Rippen sind die Klebefläche. Auf einer ebenen Platte trocknen lassen (kein Verzug).
2. **Höhenflosse:** CFK-Stab Ø 4 mm durch beide Hälften (Holmbohrung 30 mm hinter der Vorderkante) kleben; Hälften in der Mitte stumpf
   verkleben (Endrippen). **Höhenruder:** 2-mm-Stab (370 mm) durch beide Nasen (Bohrung auf der Scharnierachse) **und durch die Querbohrung
   in der Seitenflosse** (die Ruder sitzen links/rechts der Flosse, 6,5 mm Abstand), Stab nur in den Rudernasen verkleben, damit
   er in der Flosse frei dreht. Horn in den Schlitz der **linken** Unterseite (Lage y = 34 mm); Scharnierband beidseitig.
3. **Seitenflosse/-ruder mit Ruderwelle:** Das Seitenruder wird über eine **Welle in der Scharnierachse** angelenkt
   (Ø 2-mm-Federstahl, 95 mm). In beiden Schalen von Ruder und Flosse ist dafür eine Halbrinne in der Teilungsebene.
   * Seitenruderschalen verkleben und die Welle dabei in die Rinne des Ruders **einkleben** (Epoxy). Sie ragt unten
     ca. 50 mm heraus.
   * Flossenschalen um die Welle herum verkleben. Die Rinne in der Flosse ist das Lager: **kein Kleber an die Welle**
     (vorher mit etwas Vaseline/Trennwachs einreiben).
   * Seitenruder zusätzlich mit Scharnierband (beidseitig) an der Flosse sichern. Die Welle schaut unten ca. 17 mm aus dem
     Flossenfuß heraus.
4. Ruderausschläge probeweise von Hand: Höhenruder und Seitenruder müssen frei laufen (±30° geprüft).

## 3. Rumpf

Der Rumpf besteht aus 6 Segmenten mit je linker/rechter Hälfte. **Erst Hälften verkleben, dann Segmente verbinden.**

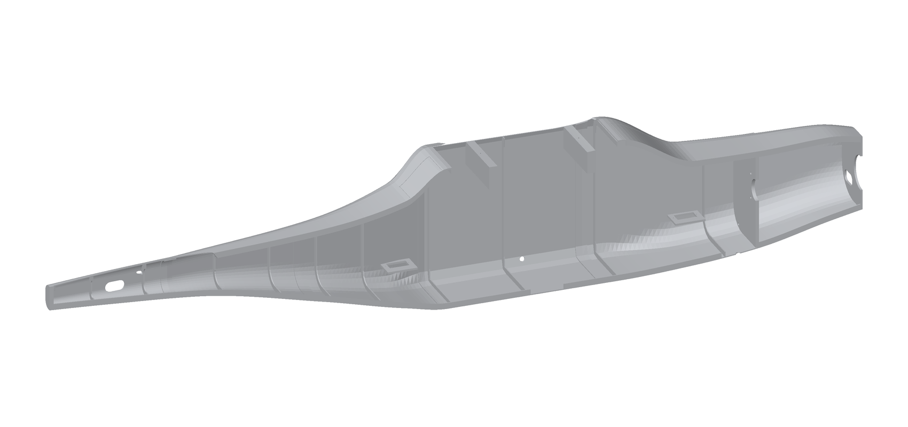
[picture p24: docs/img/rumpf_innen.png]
Rumpf innen


1. **Hälften:** Je Segment links+rechts an der Naht verkleben (Klebeflansch oben/unten, Spanten und Wände). Dabei auf
   einer ebenen Fläche liegen lassen und mit Klammern/Gewebeband fixieren. Segmente nach dem Verkleben auf Maß prüfen
   (Muffen dürfen nicht klemmen).
2. **Segmente verbinden:** `F2` → `F3` → `F4` → `F5` → `F6` über die Steckmuffen (jeweils nach hinten in das nächste
   Segment). Trocken stecken, Rumpf auf Geradheit prüfen (Blick von vorn/oben), dann mit Epoxy/Sekundenkleber
   verkleben. **Nach dem Aushärten:** Flügel probehalber auflegen (er sitzt in einem Sattel exakt auf der Kabine).
3. **Motorhaube `F1`** wird nur am Brandschott verschraubt (4× M2,5 × 10 von innen durch den Brandschott in die Dome der Haube);
   deshalb nur die beiden Hälften von `F1` miteinander verkleben.
4. **Servoböden:** In `F4` (x = 538) sitzen zwei Servoböden (links: Höhenruder, rechts: Seitenruder), in `F2` links
   der Bugradservo (x = 190). Servos mit **Abtrieb nach oben** einhängen (Flansch liegt auf dem Boden) und mit zwei
   M2-Blechschrauben fixieren.
5. **Gestänge Heck:** Zwei Kanäle (Ø 3,8 mm) führen von den Servohebeln (Loch 10 mm, Hebel zur Rumpfmitte) durch die Spanten.
   * **Höhenruder (links):** Bowdenzug-Außenrohr Ø 3/2 mm im Kanal bis in das **schräge Austrittsloch links am Heck**
     (x ≈ 865 mm), dort bündig einkleben; Stahlseele Ø 1,2 mm, außen Gabelkopf zum Horn.
   * **Seitenruder (rechts):** CFK-Stab Ø 2 mm mit angeklebten Stahldraht-Enden (Ø 1,5) bleibt **im Rumpf** und endet am
     Seitenruderhebel `S4` (Montage in Abschnitt 6).
   * `F6` links hat eine **Wartungsöffnung** (24 × 12 mm): Dort erreichst du die Madenschraube von `S4` und den Gabelkopf.
     Später mit Klebeband abdecken.
6. **Brandschott:** Der Brandschott (4 mm, Teil von `F2`) trägt Motorbock und Haube. Lochbild für den Motorbock:
   4 × M3 auf 30-mm-Quadrat.

## 4. Antrieb

Teile: `P1` Motorbock, `P2` Spinnerkegel, `P3` Spinnerplatte.

1. Motor an die **Vorderseite** des Motorbock-Flansches schrauben (16- oder 19-mm-Kreuz, 4× M3 × 8).
   Motorkabel durch den Hohlraum des Bocks nach hinten führen (der Bock lässt Kühlluft durch die 6 Schlitze).
2. Motorbock mit 4× M3 × 10 an den Brandschott (30-mm-Quadrat). Motorwelle liegt dann in der Haubenmitte; der Glockenrand
   steht bündig hinter der Haubenvorderkante (Hauben-Ausschnitt Ø 42 mm).
3. Regler im Haubeninneren **unter dem Motorbock** (Klett, x ≈ 70–120 mm), Kabelweg durch die Löcher im Brandschott.
4. Propelleradapter mit **Spinnerplatte** montieren (Platte direkt hinter der Luftschraube), Luftschraube,
   **Spinnerkegel** mit 4× M2,5 × 10 auf die Platte. Die Blätter laufen durch die Aussparungen am Rand des Kegels.

## 5. Fahrwerk

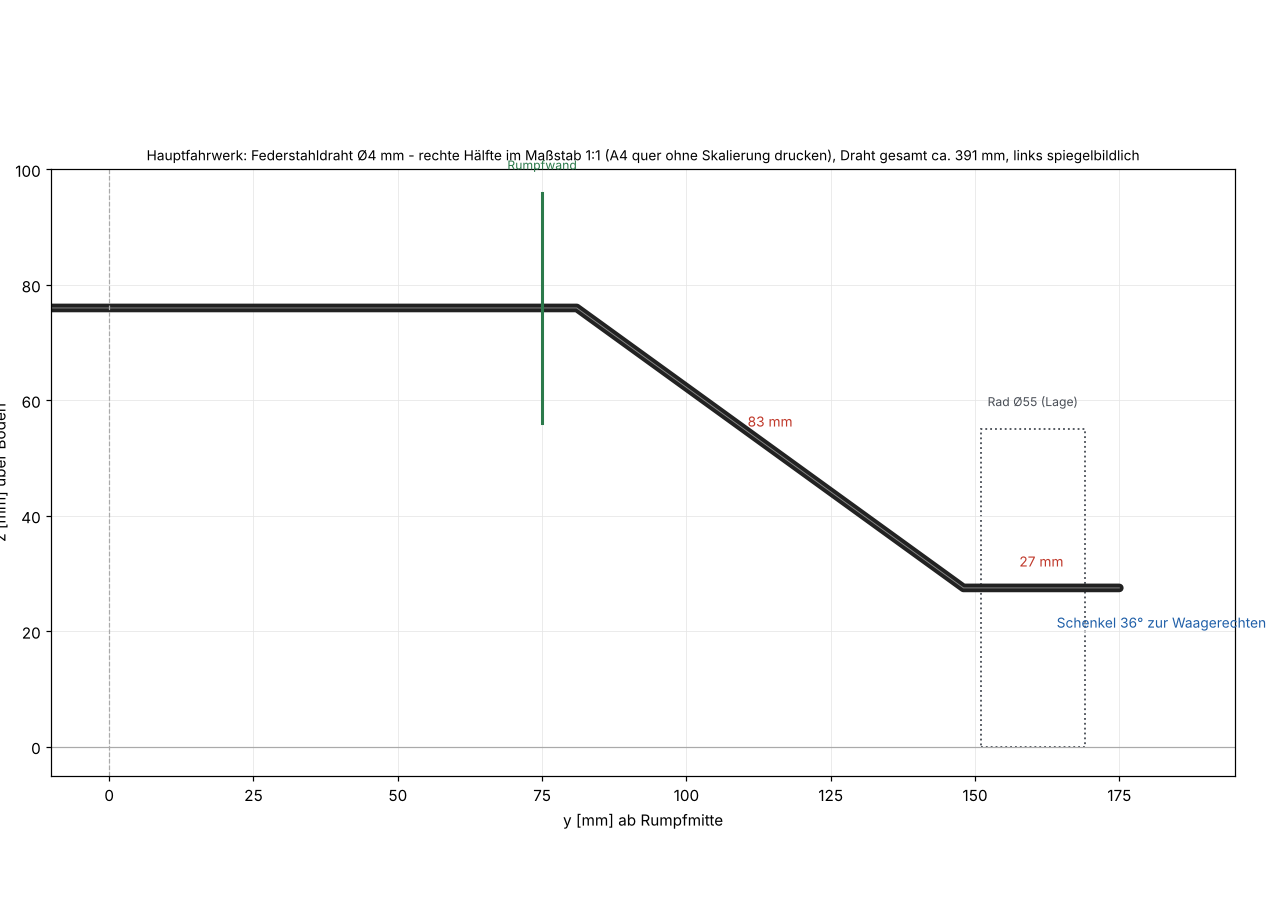
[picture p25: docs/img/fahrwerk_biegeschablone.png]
Biegeschablone


**Hauptfahrwerk:** 4-mm-Federstahldraht nach `docs/fahrwerk_biegeschablone.pdf` biegen (rechte Hälfte 1:1, links gespiegelt).
Der Draht verläuft als Brücke quer durch den Rumpf (Höhe z = 76 mm) und tritt durch zwei Löcher in den Seitenwänden
aus; die Schenkel gehen mit ca. 37° nach unten zu den Achsstummeln.

1. Untere Klemme `G3` auf den Rumpfboden von `F3` kleben (Lage x = 382 ± 15; sie überbrückt die Naht).
2. Draht durch die Wandlöcher legen, in die Nut der Klemme drücken, obere Klemme `G4` mit 2× M3 × 12 festschrauben.
3. Räder: Reifen (TPU) auf die Naben (`G2`) kleben, Naben auf die Achsstummel (Stellringe außen und innen).

**Bugfahrwerk:** Gabel `G7` (Brücke nach unten drucken!) über das untere Ende des 3-mm-Drahts (56 mm) kleben; Achse Ø 3 mm
durch Gabel und Nabe; Lager `G5` auf den Rumpfboden und an den Brandschott kleben (Bohrung Ø 3,5 für den Draht); oben
sitzt der Lenkhebel `G6` mit M3-Madenschraube; Gestänge Ø 1,2 mm (61 mm) vom Bugradservo zum Hebel. Das Bugradservo
sitzt mit der **Welle nach vorn** im Servoboden, Hebel (Loch 14 mm) zeigt nach vorn. Das Anlenkloch in `G6` ist senkrecht
für einen Z-Bügel.

Empfohlener Lenkausschlag ca. ±30°. Das Bugradservo läuft über ein **Y-Kabel am Seitenruderkanal** oder über einen eigenen Kanal
(siehe `docs/FERNSTEUERUNG.md`).

**Radverkleidungen (optional):** `G8` (Haupträder, je innen/außen) und `G9` (Bugrad) paarweise verkleben. Die
Hauptrad-Verkleidung wird über das Drahtende geschoben (innen ist ein Schlitz für den Fahrwerksschenkel), Rad
dazwischen, Stellring außen; die Verkleidung mit einem Tropfen Sekundenkleber am Draht gegen Verdrehen sichern.
Die Bugrad-Verkleidung sitzt auf der Achse zwischen Gabel und Stellringen, die Gabel ragt oben durch den Schlitz.

## 6. Endmontage

1. **Leitwerk:** Seitenflosse `S1` senkrecht von oben in den Schlitz der Heckwand (die untersten 12–18 mm der Flosse
   stecken im Heck) stecken, ausrichten (Lot, Draufsicht) und verkleben. Höhenflossenhälften seitlich an die Flosse
   und auf die Heckwand kleben; **Einstellwinkel 0°** gegenüber der Rumpf-Längsachse kontrollieren.
   Die Ruderwelle zeigt dabei durch den Flossenschlitz nach unten in den Rumpf. **Seitenruderhebel `S4`** durch die
   Wartungsöffnung (links am Heck) auf das Wellenende schieben, Arm nach rechts. Seitenruder neutral stellen und die
   M3-Madenschraube anziehen. Dann den Gabelkopf des Seitenrudergestänges einhängen.
   Zum Schluss die **Rückenflosse** `S3` mittig auf den Rumpfrücken (ab x = 690 mm) und an die Vorderkante der Seitenflosse kleben.
2. **Flügel:** Auf den Sattel legen; 4× M3 × 20 durch die Dome in `W0` (x = 327 / 445 mm, y = ±38 mm) in die Spantbalken des Rumpfes
   schrauben. Servokabel in die Kabine führen.
3. **Streben (optional):** `Z1_Strebe_rechts/links` mit Epoxy an die Rumpfseitenwand (z = 110 mm) und die Flügelunterseite
   (Stoß W1/W2, x = 78 mm hinter der Flügelvorderkante) kleben. Sie sind **kosmetisch** und tragen kaum Last.
4. **Akku:** Längs im Bugfach (x ≈ 170–283 mm), Einschub von der Kabine aus nach vorn, mit Klettband sichern;
   so lässt sich der Schwerpunkt über die Akkulage (und Trimmblei) einstellen.
5. **Empfänger:** mit Klett an die rechte Kabinenwand (x ≈ 220–260 mm); Antennen 90° zueinander, weg von Regler/Motor.
   Kanalbelegung, Y-Kabel und Senderprogrammierung: `docs/FERNSTEUERUNG.md`.

## 7. Schwerpunkt und Einstellungen

<!-- AUTO:schwerpunkt -->
| Größe | Wert |
|---|---|
| **Schwerpunkt** | **60 mm hinter der Flügelvorderkante** (Rechenwert 355 mm hinter der Haubenvorderkante); zulässig: 44–65 mm = 24–35 % MAC |
| MAC | 185 mm |
| Auswiegen | Flugzeug an den Punkten bei **x = 355 mm** (am Rumpf von der Haubenvorderkante gemessen) unterstützen, Nase leicht unten |
<!-- /AUTO:schwerpunkt -->

Ist die Nase zu leicht: Akku nach vorn, bei Bedarf Trimmblei (Klett) im Bug (Motorhaube); 20 g im Bug verschieben den
Schwerpunkt um ca. 4 mm nach vorn.

| Ruder | Ausschlag | Expo |
|---|---:|---:|
| Querruder | ± 15° (niedrig ± 10°) | 30 % |
| Höhenruder | ± 15° (niedrig ± 10°) | 25 % |
| Seitenruder | ± 20° | 20 % |
| Landeklappen | Start 15°, Landung 35° (nach unten); Höhenruder bei Klappe 2–3° tiefer mischen | – |
| Bugrad | ± 30° (mit dem Seitenruder) | – |

Ausschläge in mm an der Hinterkante, Servoweg, Failsafe und Drehrichtungs-Check: `docs/FERNSTEUERUNG.md`.
Motor erst ohne Luftschraube prüfen (Drehrichtung, Failsafe). Reichweite testen.

## 8. Erstflug

* Ungeprüfter Entwurf! Das Flugzeug wurde **gebaut und gerechnet, aber nicht geflogen**. Gewichte, Schwerpunkt und
  Leistung sind Rechenwerte. Rechne mit Abweichungen und Probeflügen. Erstflug bei Windstille, Gras, mit Erfahrung.
* Reserve: Das Modell hat nur ca. 0,5–0,6 Schub/Gewicht (Richtwert) und 64 g/dm² Flächenbelastung; Überziehgeschwindigkeit ca. 9 m/s.
  Starte mit Vollgas gegen den Wind und steige flach.
* Prüfe nach jedem Flug Scharniere, Holm-Verklebung, Fahrwerksdraht und Schrauben.

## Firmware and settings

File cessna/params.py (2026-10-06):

"""Zentrale Maße des Modells (mm). Vorbild: Cessna 172, Maßstab 1:8.

Koordinaten im Zusammenbau: x nach hinten (x=0 = Haubenvorderkante, Spinner davor),
y nach rechts (Pilotensicht), z nach oben (z=0 = Boden bei stehendem Flieger).
"""
import numpy as np

SCALE = 8

# --------------------------------------------------------------------------- #
# Drucker / Material
# --------------------------------------------------------------------------- #
BED = (220.0, 220.0, 250.0)         # nutzbares Druckvolumen x, y, z
BED_MARGIN = 4.0                    # Rand, den ein Teil mindestens zum Bettrand hält
WALL_FUSE = 1.2                     # Außenhaut Rumpf (3 Perimeter @0,4 mm)
WALL_WING = 1.1                     # Außenhaut Flügel/Leitwerk an der Wurzel
RIB_T = 1.2                         # Rippendicke
CLEAR = 0.25                        # Passungsspiel für Steckverbindungen
DENSITY = {"LW-PLA": 0.55, "PLA": 1.24, "PETG": 1.27, "TPU": 1.20}   # g/cm³ im Bauteil (Schätzung)

# --------------------------------------------------------------------------- #
# Flügel (NACA 2412, gerade Vorderkante, Innenteil rechteckig, außen verjüngt)
# --------------------------------------------------------------------------- #
WING_AIRFOIL = "2412"
WING_FLAT_FROM = 0.25               # gerader Unterseitenboden ab 25 % Tiefe (druckfreundlich)
WING_SEMISPAN = 687.5               # 11,0 m / 8 / 2
WING_ROOT_CHORD = 200.0             # 1,63 m / 8 (gerundet)
WING_TIP_CHORD = 140.0              # 1,12 m / 8
WING_TAPER_START = 300.0            # y, ab hier verjüngt
WING_LE_X = 295.0                   # Flügelvorderkante im Rumpf (bestimmt Schwerpunktlage)
WING_INCIDENCE = 2.0                # Einstellwinkel (Grad, Nase hoch)
WING_Z_REF = 240.0                  # Höhe der Profilsehne an der Flügelnase im Zusammenbau
WING_CENTER_HALF = 80.0             # Mittelstück reicht von -80 bis +80
WING_PANEL_SPAN = (WING_SEMISPAN - WING_CENTER_HALF) / 3.0   # 202,5
SPAR_X = 55.0                       # Holmachse hinter der Vorderkante
SPAR_Z = 3.0                        # Holmachse über der Profilsehne
SPAR_OD, SPAR_ID = 10.0, 8.0        # CFK-Rohr 10/8 mm
SPAR_BORE = SPAR_OD + 0.4           # Bohrung
SPAR_SLEEVE_OD = 13.0               # gedruckte Holmhülse
JOINER_D = 8.0                      # CFK-Stab als Flächenverbinder (in Rohr 10/8)
AIL_Y0, AIL_Y1 = 330.0, 650.0       # Querruder von/bis
AIL_Y_SPLIT = WING_CENTER_HALF + 2 * WING_PANEL_SPAN   # 485: Plattenstoß -> Querruder in 2 Teilen
AIL_CHORD_FRAC = 0.28               # Querruderanteil an der Flügeltiefe
HINGE_GAP = 1.6
SERVO_9G = dict(L=23.2, W=12.4, H=22.8, flange_L=32.5, flange_T=2.4, flange_off=6.0)
AIL_SERVO_Y = 352.0                 # Servomitte (spannweitig)
AIL_SERVO_X = 80.0                  # Servomitte hinter der Vorderkante
FLAP_Y0, FLAP_Y1 = 84.0, 278.5      # Landeklappe (im Abschnitt W1, gleiche Scharnierlinie wie Querruder)
FLAP_SERVO_Y = 150.0                # Servomitte Klappenservo
FLAP_DOWN_MAX = 35.0                # maximaler Klappenausschlag nach unten (Grad)
WING_BOLT_X = (32.0, 150.0)         # Schraubenpositionen hinter der Flügelvorderkante
WING_BOLT_Y = 38.0                  # +/- y der Flügelschrauben (M3)
STRUT_Y = 282.5                     # Strebenansatz am Flügel (Plattenstoß)
STRUT_X = 78.0                      # hinter der Flügelvorderkante
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

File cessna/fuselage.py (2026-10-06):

"""Rumpf: Rundrechteck-Querschnitte, Schale mit konstanter Wand, in Segmente und Hälften geteilt."""
from __future__ import annotations

import numpy as np
from scipy.interpolate import PchipInterpolator

from . import geom as g
from . import tail as tail_mod
from . import wing as wing_mod
from .geom import CrossSection, Manifold
from .params import *
from .parts import Part

T = WALL_FUSE
M = 72                                     # Punkte pro Querschnitt (durch 4 teilbar -> Symmetrie)
TH = np.linspace(0, 2 * np.pi, M, endpoint=False)

_tx = FUSE_TABLE[:, 0]
_W = lambda x: np.interp(x, FUSE_WIDTH_NODES[:, 0], FUSE_WIDTH_NODES[:, 1])   # Seitenwände eben
_ZB = PchipInterpolator(_tx, FUSE_TABLE[:, 2])
_ZT = PchipInterpolator(_tx, FUSE_TABLE[:, 3])
_RC = PchipInterpolator(_tx, FUSE_TABLE[:, 4])


# --------------------------------------------------------------------------- #
# Querschnitte
# --------------------------------------------------------------------------- #
def section(x):
    x = np.atleast_1d(np.asarray(x, float))
    w, zb, zt, rc = _W(x), _ZB(x), _ZT(x), _RC(x)
    rc = np.minimum(rc, 0.499 * np.minimum(w, zt - zb))
    return w, zb, zt, rc


def ring_yz(x, inset=0.0) -> np.ndarray:
    """Querschnittspunkte (S, M, 2) = (y, z) als Rundrechteck, um `inset` verkleinert."""
    w, zb, zt, rc = section(x)
    a = np.maximum(w / 2 - inset, 0.3)
    b = np.maximum((zt - zb) / 2 - inset, 0.3)
    r = np.clip(rc - inset, 0.25, np.minimum(a, b) - 0.01)
    zc = (zt + zb) / 2
    d0, d1 = np.cos(TH)[None, :], np.sin(TH)[None, :]
    lo = np.zeros((len(a), M))
    hi = np.full((len(a), M), float((a + b).max() + 10))
    ia, ib = (a - r)[:, None], (b - r)[:, None]
    for _ in range(34):
        t = (lo + hi) / 2
        qx = np.maximum(np.abs(t * d0) - ia, 0)
        qz = np.maximum(np.abs(t * d1) - ib, 0)
        out = (np.hypot(qx, qz) - r[:, None]) > 0
        hi = np.where(out, t, hi)
        lo = np.where(out, lo, t)
    t = (lo + hi) / 2
    return np.stack([t * d0, zc[:, None] + t * d1], axis=-1)


def grid(x0, x1, step=5.0):
    xs = set(np.arange(0, FUSE_LEN + 0.01, step)) | set(_tx) | {x0, x1}
    xs = np.array(sorted(v for v in xs if x0 - 1e-9 <= v <= x1 + 1e-9))
    return xs


def body(x0, x1, inset=0.0) -> Manifold:
    xs = grid(x0, x1)
    yz = ring_yz(xs, inset)
    rings = np.concatenate([xs[:, None, None] * np.ones((1, M, 1)), yz], axis=-1)
    return g.loft_rings(rings)


def poly_yz(x, inset=0.0) -> np.ndarray:
    return ring_yz([x], inset)[0]


def slab_x(cs: CrossSection, x0: float, thick: float) -> Manifold:
    """Querschnitt (Rahmen: X=y, Y=z) entlang x von x0 bis x0+thick extrudieren."""
    m = Manifold.extrude(cs, thick)
    Tm = np.array([[0, 0, 1, x0], [1, 0, 0, 0], [0, 1, 0, 0], [0, 0, 0, 1.0]])
    return g.apply(m, Tm)


def ring_frame(x, thick=FRAME_T, width=FRAME_W, in0=T - 0.1):
    """Ringspant bei x: Band zwischen Innenfläche und Innenfläche + width (voll bei engen Querschnitten)."""
    w, zb, zt, rc = section(x)
    h_in = float(zt[0] - zb[0]) - 2 * T
    wd = min(width, 0.5 * min(float(w[0]) - 2 * T, h_in) - 1.8)
    outer = CrossSection([g.ccw(poly_yz(x, in0))])
    if wd < 0.8:
        return slab_x(outer, x, thick)
    inner = CrossSection([g.ccw(poly_yz(x, T + wd))])
    return slab_x(outer - inner, x, thick)


def ref_frame_pt(x, ang_deg, inset):
    """Punkt auf dem um `inset` verkleinerten Querschnitt in Richtung ang_deg (0 = +y, 90 = +z)."""
    pts = ring_yz([x], inset)[0]
    i = int(round(ang_deg / 360.0 * M)) % M
    return pts[i]


# --------------------------------------------------------------------------- #
# Aufbau des gesamten Rumpfes
# --------------------------------------------------------------------------- #
def wing_clear() -> Manifold:
    s = wing_mod.make_surface()
    sol = s.prism(-WING_CENTER_HALF - 1.0, WING_CENTER_HALF + 1.0, False)
    sol = g.apply(sol, wing_mod.wing_asm_T())
    return sol + sol.translate((0, 0, -0.25))


def roof_hole() -> Manifold:
    """Dachöffnung unter dem Flügelmittelstück; seitlich bleibt ein schmaler Rand für die Auflage."""
    xs = np.linspace(*CABIN_OPEN_X, 20)
    w, zb, zt, rc = section(xs)
    half = float((w / 2 - rc).min()) - 1.5
    return g.box(CABIN_OPEN_X[0], CABIN_OPEN_X[1], -half, half, 120.0, 320.0)


def build_core() -> Manifold:
    outer = body(0.0, FUSE_LEN, 0.0)
    inner = body(2.4, FUSE_LEN - 5.0, T)
    hole = roof_hole()
    a_max = 0.5 * float(section(np.linspace(*CABIN_OPEN_X, 20))[0].max())
    shell = outer - (inner + hole)

    parts = [shell]

    # ---- Spanten ------------------------------------------------------------ #
    for x in FRAME_X:
        parts.append(ring_frame(x))

    # ---- Spantenbalken für die Flügelschrauben ------------------------------- #
    Tw = wing_mod.wing_asm_T()
    beam_holes = []
    for bx in WING_BOLT_X:
        xb = WING_LE_X + bx
        beam = g.box(xb - 5.0, xb + 5.0, -(a_max - T + 0.5), a_max - T + 0.5, 205.0, 250.0) ^ outer
        parts.append(beam)
        for sy in (-1, 1):
            p_top = (Tw @ np.array([bx, sy * WING_BOLT_Y, 40.0, 1.0]))[:3]
            p_bot = (Tw @ np.array([bx, sy * WING_BOLT_Y, -30.0, 1.0]))[:3]
            beam_holes.append(g.cyl(p_bot, p_top, 1.25, segs=24))

    # ---- Klebeflansch an der Teilungsebene y = 0 ---------------------------- #
    xs = grid(0.0, FUSE_LEN, 5.0)
    w, zb, zt, rc = section(xs)
    wb = np.clip(0.5 * (zt - zb) - T - 1.0, 0.0, FRAME_W)
    for top in (True, False):
        # Streifen in zusammenhängende Abschnitte zerlegen
        runs, cur = [], []
        for i, x in enumerate(xs):
            skip = (top and CABIN_OPEN_X[0] - 6 <= x <= CABIN_OPEN_X[1] + 6) or \
                   (not top and any(a <= x <= b for a, b in FLANGE_GAPS_BOTTOM))
            if skip:
                if len(cur) > 1:
                    runs.append(cur)
                cur = []
            else:
                cur.append(i)
        if len(cur) > 1:
            runs.append(cur)
        for run in runs:
            if top:
                hi = [(xs[i], zt[i] - T + 0.3) for i in run]
                lo = [(xs[i], zt[i] - T - wb[i]) for i in run]
            else:
                hi = [(xs[i], zb[i] + T + wb[i]) for i in run]
                lo = [(xs[i], zb[i] + T - 0.3) for i in run]
            polyxy = hi + lo[::-1]
            m = Manifold.extrude(CrossSection([g.ccw(polyxy)]), 2 * FLANGE_T)       # Rahmen (x, z) -> Extrusion = y
            Tm = g.rot_x(90)                                                         # (x,y,z) -> (x,-z,y)
            m = g.apply(m, Tm).translate((0, FLANGE_T, 0))
            parts.append(m ^ outer)

    whole = g.union(parts)
    whole = g.difference(whole, *beam_holes)
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

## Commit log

2026-10-06 1:8 Cessna-172-Style RC-Flugzeug zum 3D-Druck (parametrischer Generator + STL)
    Einmotoriger Hochdecker, Spannweite 1375 mm, Druckbett ab 220x220 mm.
    - Python-Generator (manifold3d/trimesh): Flügel (4 Abschnitte, CFK-Holm,
    Querruder mit Rundnase/Hohlkehle, Servoschächte), Rumpf (6 Segmente links/
    rechts mit Steckmuffen, Flügel als Kabinendach), Leitwerk (Ober-/Unterschalen),
    Antrieb (Motorbock, Spinner), Fahrwerk (Räder, Klemmen, Bugfahrwerk), Streben
    - 48 STL-Dateien in Druckausrichtung (wasserdicht geprüft), Druckliste, Stückliste
    - Dokumentation: Bauanleitung, Druckeinstellungen, Zukaufteile, Biegeschablone
    - Prüfungen (pytest): Gültigkeit, Druckbettgröße, Überschneidunge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
    [F1_Motorhaube_links.stl, F1_Motorhaube_rechts.stl, F2_Bug_links.stl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]
2026-10-06 Hinterkante druckbar (1,0-1,5 mm), robustere Rudernasen, mehrstufiger STL-Export, Doku-Zahlen aktualisiert
    Claude-Session: https://claude.ai/code/session_019YyEih1dJW5N6zxAw3iCh6
    [F2_Bug_links.stl, F2_Bug_rechts.stl, F3_Kabine_links.stl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]
2026-10-06 Druckausrichtung der verjüngten Flügelabschnitte nach tatsächlicher Bodenebene, Einkörperigkeitsprüfung, flachere Streben/Reifen
    - Flügelabschnitte W2/W3 und Querruder liegen jetzt exakt flach (Bodenebene spanweise geneigt)
    - Prüfung: genau ein Festkörper je Teil; schwebende Reste im Leitwerk entfernt
    - Reifen mit ebener Seite, Bugfahrwerkslager auf ebener Fläche, Streben mit Auflagefläche
    - Neuer Test für die Druckausrichtung
    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
    [G1_Reifen.stl, G5_Bugfahrwerkslager.stl, Q1_Querruder_innen_links.stl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]
2026-10-06 Landeklappen, Radverkleidungen, Rückenflosse und 3D-Ansicht im Browser
    - Landeklappen im Innenflügel W1 (eigener Servoschacht, 0..35° frei beweglich, geprüft)
    - Radverkleidungen für Haupt- und Bugrad (Hälften, druckbar ohne Stützen)
    - Rückenflosse als flach gedrucktes Teil zwischen Rumpfrücken und Seitenflosse
    - docs/viewer: interaktive 3D-Ansicht (three.js) mit Ruderbewegung, Explosionsansicht,
    Baugruppen, Schwerpunkt und Teileliste; GLB + teile.json werden beim Build erzeugt
    - Doku (README, Bauanleitung, Zukaufteile) und Kennzahlen aktualisiert
    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
    [G8_Radverkleidung_links_aussen.stl, G8_Radverkleidung_links_innen.stl, G8_Radverkleidung_rechts_aussen.stl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]
2026-10-06 RC-Anlenkung komplett vorbereiten, Zukaufteile in der 3D-Ansicht
    - Neues Modul cessna/linkage.py: Servo-, Hebel-, Horn- und Gestängegeometrie aus dem Modell;
    Kinematik mit fester Gestängelänge wählt das Hebel-Loch und prüft die Sollausschläge
    - Seitenruder über Ruderwelle (Ø2-Draht in der Scharnierachse) und Hebel S4 im Heck,
    Gestänge bleibt im Rumpf; Wartungsöffnung links; Scharnierlinie 8 mm nach hinten
    (Abstand zum Höhenruder-Verbinder)
    - Höhenruder: Bowdenzug mit schrägem, auf das Gestänge ausgerichtetem Austrittsloch
    (vorher hätte das Gestänge die Rumpfwand gekreuzt)
    - Bugrad: Servo mit Welle vorn, Anlenkloch in G6 senkrecht; Hebel G6/S4 flach druckbar
    - Servobö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
    [F2_Bug_links.stl, F4_Rumpfmitte_links.stl, F4_Rumpfmitte_rechts.stl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]
2026-10-06 Druckfertige 3MF-Druckplatten für 220 × 220-mm-Betten
    - cessna/plates.py: alle Teile nach Material/Slicer-Einstellung gruppiert, mit MaxRects
    auf dem Bett angeordnet (4 mm Rand, 8 mm Abstand für Brim) und als 3MF geschrieben
    (exakte float32-Koordinaten, deterministisch)
    - druckplatten/: 34 Platten (LW-PLA Flügel/Leitwerk/Rumpf/Verkleidung, PETG, PETG massiv,
    PLA, TPU); Platte 01 = W0 als Probedruck zum Wiegen
    - docs/DRUCKPLATTEN.md mit Einstellungen je Platte, Übersichtsbild docs/img/druckplatten.png
    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
    [01_LW-PLA_Fluegel_W0_Mittelstueck.3mf, 02_LW-PLA_Fluegel_W2_links.3mf, 03_LW-PLA_Fluegel_W2_rechts.3mf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]
